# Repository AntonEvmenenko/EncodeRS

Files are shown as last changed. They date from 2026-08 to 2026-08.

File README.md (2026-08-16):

# EncodeRS

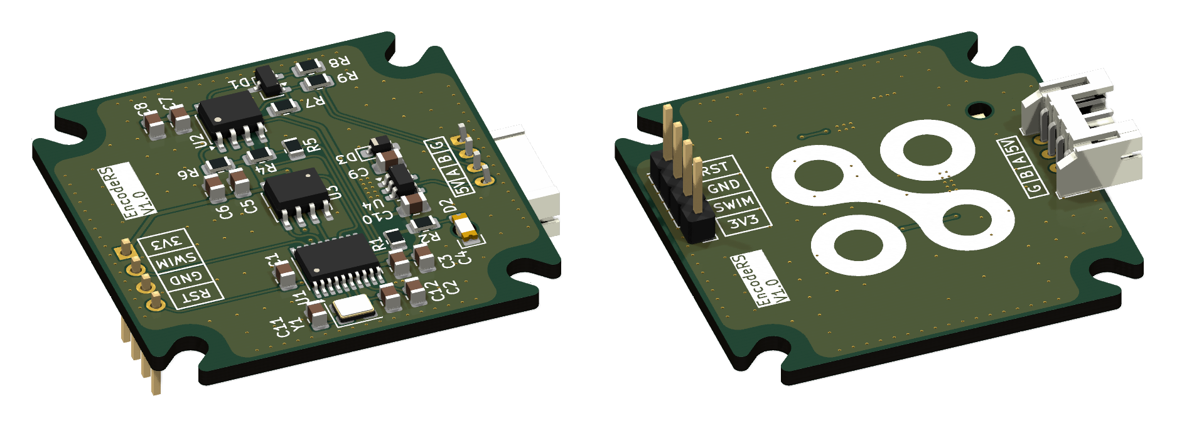
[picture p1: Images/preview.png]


**A dirt-cheap, minimal-component RS485 magnetic encoder designed to sit right on the back of a Nema 17 stepper motor.**

Building a closed-loop stepper system or a FOC (Field Oriented Control) setup? This board gives you high-speed, noise-immune angle data without breaking the bank. By using RS485, it ignores the nasty electromagnetic interference (EMI) generated by the motor coils, even over long cables.

## Key Features
*   **Ultra-Low Cost:** Designed with minimal BOM in mind. No fancy or redundant components.
*   **Hand-Assembly Friendly:** SMD components smaller than 0805 were avoided wherever possible, so you don't need eagle eyes or a microscope to build it yourself.
*   **Noise Immune:** RS485 differential signaling ensures your angle data survives the electrically noisy environment right next to a spinning motor.
*   **4-Wire Interface:** Just provide `+5V`, `GND`, and the `A`/`B` differential pair. 
*   **FOC Ready:** Offloads the motor position sensing from the main controller.

## Under the Hood
*   **Sensor:** `MT6816CT-ACD` – SPI magnetic angle sensor.
*   **MCU:** `STM8S003F3P` – Reads the SPI sensor and spits out UART.
*   **Transceiver:** `SP3485EN` – Converts UART to robust RS485.
*   **LDO:** `HT75R33-1A` – Drops the incoming 5V to a clean 3.3V for the logic.

## Project Status
- [x] Schematic design
- [x] PCB routing
- [ ] Enclosure design
- [ ] Firmware development
- [ ] Testing on a real motor under heavy load

## Acknowledgments
A big shoutout to [**dVNaNt**](https://github.com/dVNaNt) for coming up with the perfect name for this project!

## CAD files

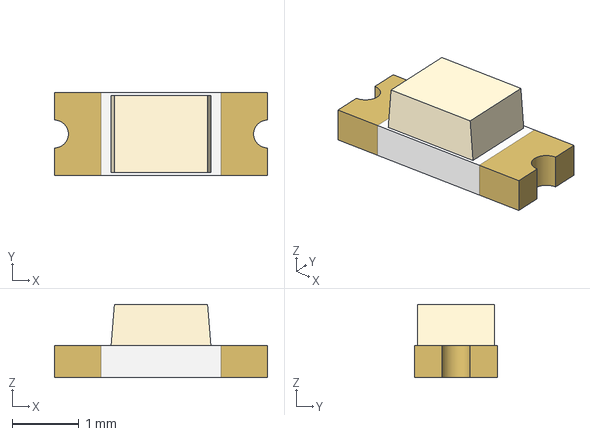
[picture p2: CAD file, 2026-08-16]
Hardware/3d_models/Amicc-A-SP151W1D-C04-3A.step
3.20 x 1.25 x 1.10 mm

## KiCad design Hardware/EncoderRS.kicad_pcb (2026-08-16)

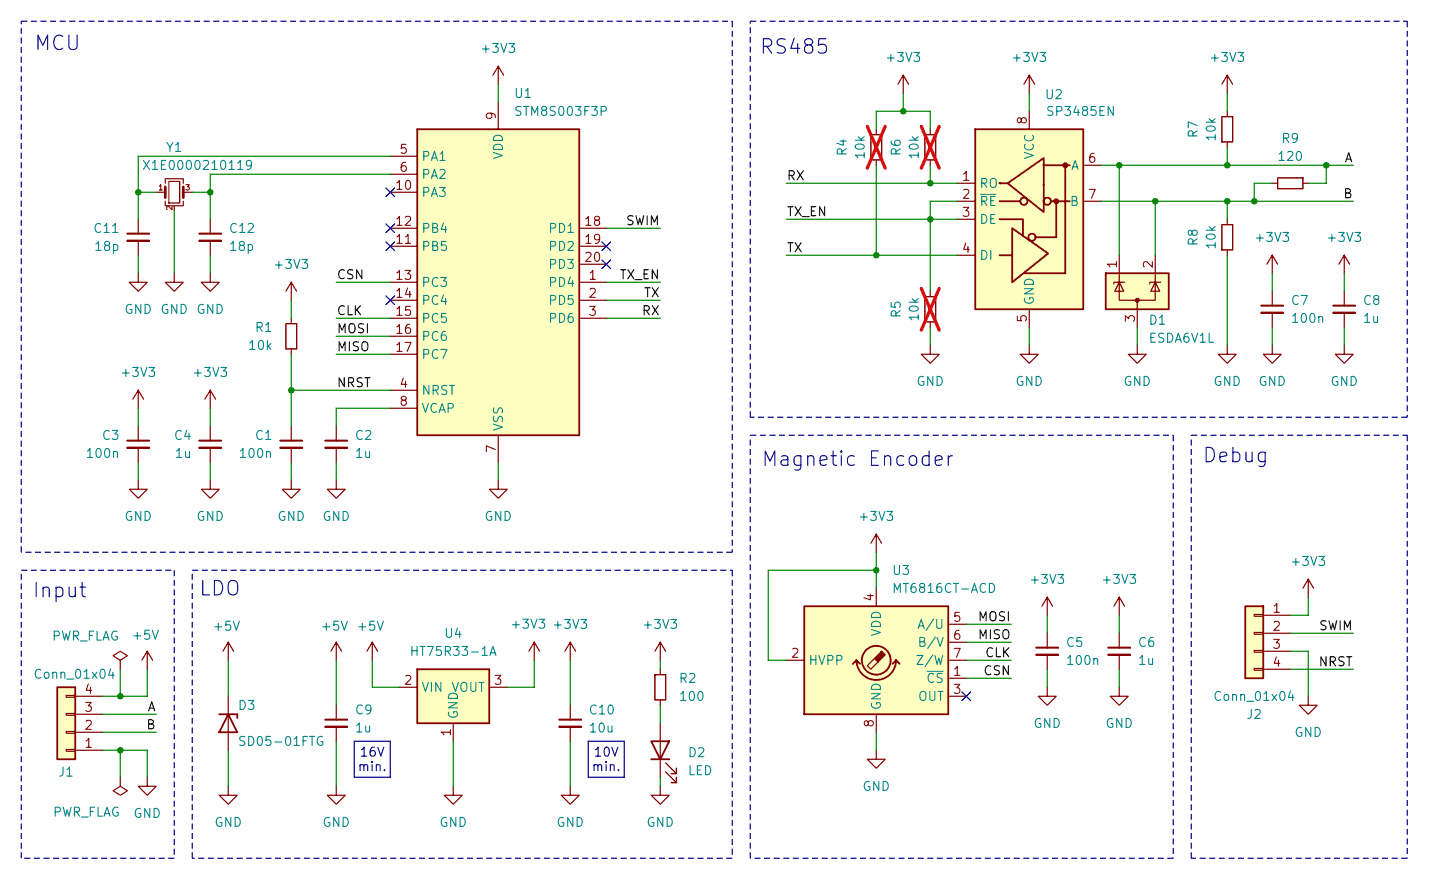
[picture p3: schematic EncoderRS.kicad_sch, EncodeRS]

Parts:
C1, C3, C5, C7: 100n; C_0805_2012Metric; LCSC Part Number C16195242
C2, C4, C6, C8, C9: 1u; C_0805_2012Metric; LCSC Part Number C24123
C10: 10u; C_0805_2012Metric; LCSC Part Number C32635
C11, C12: 18p; C_0805_2012Metric; LCSC Part Number C597363
D1: ESDA6V1L; SOT-23-3; LCSC Part Number C24378
D2: LED; LED_1206_3216Metric_ReverseMount_Hole2.1mm; LCSC Part Number C19171367
D3: SD05-01FTG; D_SOD-323_HandSoldering; LCSC Part Number C151235
J1: Conn_01x04; JST_PH_S4B-PH-K_1x04_P2.00mm_Horizontal; LCSC Part Number C157926
J2: Conn_01x04; PinHeader_1x04_P2.54mm_Vertical; LCSC Part Number C160334
R1, R7, R8: 10k; R_0805_2012Metric; LCSC Part Number C4336117
R2: 100; R_0805_2012Metric; LCSC Part Number C859139
R4, R5, R6: 10k; R_0805_2012Metric; LCSC Part Number C4336117; not fitted
R9: 120; R_0805_2012Metric; LCSC Part Number C114244
U1: STM8S003F3P; TSSOP-20_4.4x6.5mm_P0.65mm; LCSC Part Number C52717
U2: SP3485EN; SOIC-8_3.9x4.9mm_P1.27mm; LCSC Part Number C8963
U3: MT6816CT-ACD; SO-8_3.9x4.9mm_P1.27mm; LCSC Part Number C5449395
U4: HT75R33-1A; SOT-23-5; LCSC Part Number C54556441
Y1: X1E0000210119; Crystal_SMD_3225-4Pin_3.2x2.5mm; LCSC Part Number C89371

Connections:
+3V3: C3.1, C4.1, C5.1, C6.1, C7.1, C8.1, C10.1, J2.1, R1.1, R2.1, R4.2, R6.2, R7.2, U1.9 (VDD), U2.8 (VCC), U3.2 (HVPP), U3.4 (VDD), U4.3 (VOUT)
+5V: C9.1, D3.1 (K), J1.4, U4.2 (VIN)
/A: D1.1 (K), J1.3, R7.1, R9.1, U2.6 (A)
/B: D1.2 (K), J1.2, R8.2, R9.2, U2.7 (B)
/CLK: U1.15 (PC5), U3.7 (Z/W)
/CSN: U1.13 (PC3), U3.1 (~CS)
/MISO: U1.17 (PC7), U3.6 (B/V)
/MOSI: U1.16 (PC6), U3.5 (A/U)
/NRST: C1.1, J2.4, R1.2, U1.4 (NRST)
/RX: R6.1, U1.3 (PD6), U2.1 (RO)
/SWIM: J2.2, U1.18 (PD1)
/TX: R4.1, U1.2 (PD5), U2.4 (DI)
/TX_EN: R5.2, U1.1 (PD4), U2.2 (~RE), U2.3 (DE)
GND: C1.2, C2.2, C3.2, C4.2, C5.2, C6.2, C7.2, C8.2, C9.2, C10.2, C11.2, C12.2, D1.3 (A), D2.1 (K), D3.2 (A), J1.1, J2.3, R5.1, R8.1, U1.7 (VSS), U2.5 (GND), U3.8 (GND), U4.1 (GND), Y1.2 (G), Y1.4 (G)
unnamed: D2.2 (A), R2.2
unnamed: C11.1, U1.5 (PA1), Y1.1
unnamed: C12.1, U1.6 (PA2), Y1.3
unnamed: C2.1, U1.8 (VCAP)

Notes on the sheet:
Magnetic Encoder
MCU
LDO
RS485
Debug
Input
16V min.
10V min.

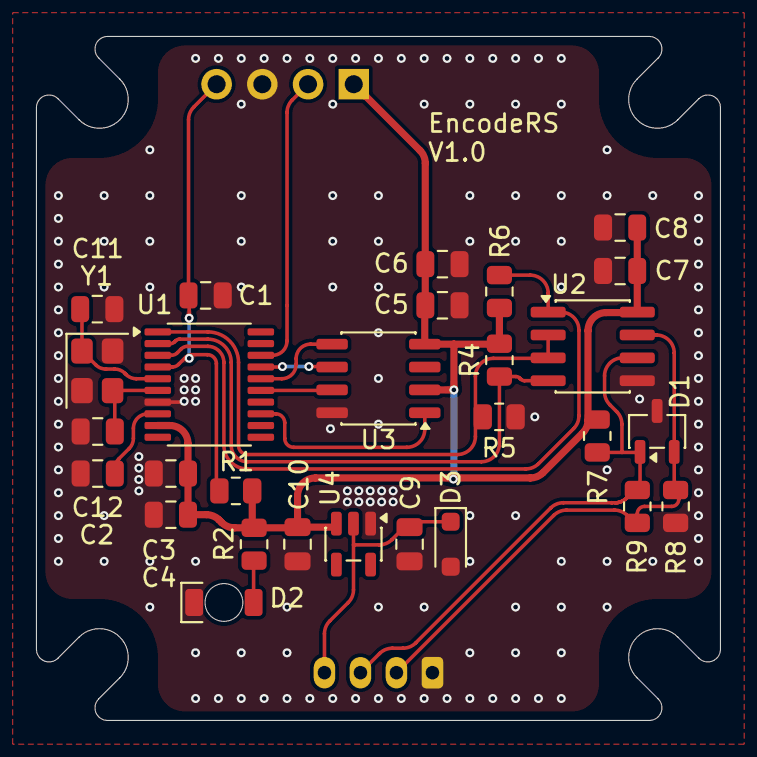
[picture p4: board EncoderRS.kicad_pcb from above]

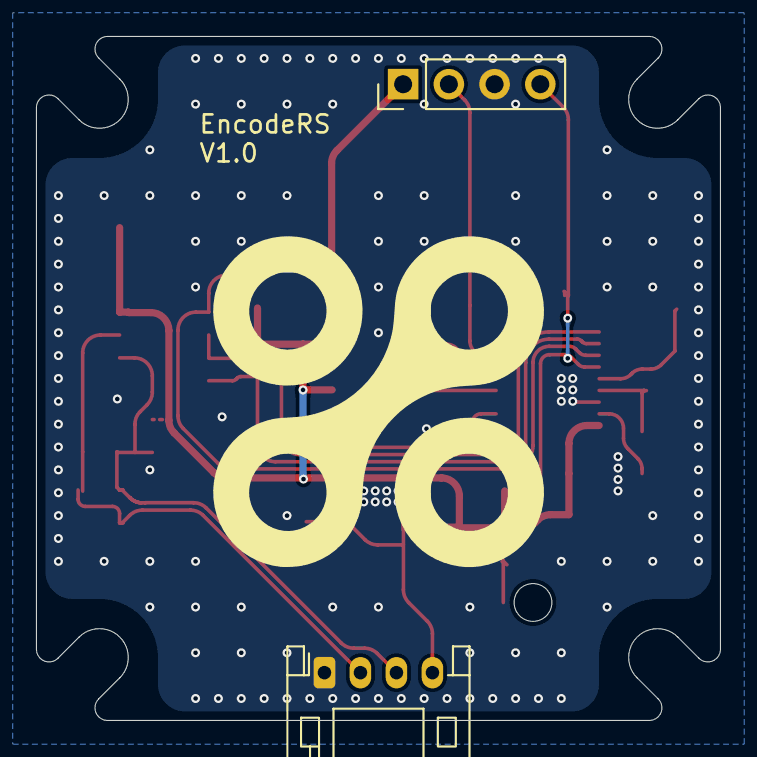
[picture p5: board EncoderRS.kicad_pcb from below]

Board: 2 copper layers, 38.0 x 38.0 mm, 30 parts (2 on the bottom side), 18 nets.

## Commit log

2026-08-16 Design is almost done
    [Amicc-A-SP151W1D-C04-3A.step, Magnetic-Encoder-RS485.kicad_pcb, Magnetic-Encoder-RS485.kicad_sch]
2026-08-16 Deleted schematic in PDF
2026-08-16 Project renamed to EncodeRS
    [EncoderRS.kicad_pcb, EncoderRS.kicad_sch]
2026-08-16 Updated libs
    [EncoderRS.kicad_pcb, EncoderRS.kicad_sch]
2026-08-16 PCB design is hopefully done
    [EncoderRS.kicad_pcb]
